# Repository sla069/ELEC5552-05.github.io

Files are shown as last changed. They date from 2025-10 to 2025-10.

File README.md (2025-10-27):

# Indoor Surveillance Drone
ELEC5552 Team 05 Indoor Surveillance Drone Project

An **autonomous indoor surveillance drone** built using the **Seeed Studio XIAO ESP32S3 Sense**, designed for **real-time monitoring, data collection, and wireless control**.  

---

## Overview

The Indoor Surveillance Drone is developed as part of a research and design project focused on indoor environmental surveillance without the use of GPS for the UWA Aviation Labs (UWAAL).  
It integrates a range of onboard sensors, live web dashboards, and local data storage to achieve semi-autonomous surveillance and sensing.

Key capabilities include:
- Real-time Wi-Fi access point (AP) control  
- Live sensor data viewing via web interface  
- Data logging in CSV format without a wired connection  
- Directional control of motors via web interface
- Live camera streaming and video recording

---

## Features

- Autonomous and manual operation modes  
- Web-based interface for live data and control  
- Wireless CSV data logging via Wi-Fi  
- Altitude, temperature, and motion sensing
- Wireless camera interface for live streaming and saving of footage to onboard microSD card

---

## Hardware Components

| Component | Description | Notes |
|---|---|---|
| **Seeed Studio XIAO ESP32S3 Sense** | Main MCU with camera and Wi-Fi | Handles all control, sensing, and communication |
| **Adafruit BMP280** | Pressure & temperature sensor | Used for altitude estimation |
| **Adafruit MPU6050** | 6-DOF IMU sensor | Provides acceleration and gyro data |
| **Li-Po Battery** | Power source | 3.7V rechargeable |
| **Drone Frame & Motors** | Propulsion system | Utilised for movement |
| **MicroSD** | Local memory | For video storage |

---

## Program Folders

This repository contains two main types of program folders, organized to make it clear which code is used for the **final demonstration** and which is for **prototyping or experiments**.

### `/src/` – Final Implemented Programs 

- Contains the **final versions** of the code used for demonstration.
- Each program is independent and can be uploaded separately to the XIAO ESP32S3.
- Subfolders:
  
/motor_control/wifi_controls.ino     → Controls drone motors and movement  
/camera_module/ESP32-CAM_MJPEG2SD.ino     → Handles camera functions and Wi-Fi streaming  
/sensor_module/combined_gyro_baro_pcb.ino       → Reads BMP280 + MPU6050 and serves web dashboard
- **Recommended for:** anyone testing or running the drone for the successfully achieved functionalities.  
- **Note:** The `camera_module` code is adapted from an open-source project ([ESP32-CAM_MJPEG2SD](https://github.com/s60sc/ESP32-CAM_MJPEG2SD)). See the `README.md` in that folder for proper attribution.

---

### `/prototype/` – Experimental and Prototype Code

- Contains **older, test, or experimental versions** of programs.
- Organized by purpose, phase, or subsystem. Example structure:

/individual_tests/→ initial motor, and sensor experiments   
/combined_versions/ → integrated tests before final firmware  
/superseded/ → older code no longer in use *(i.e for components no longer utilised in final design)*

---

## Setup and Installation

### Hardware Setup

| Connection | BMP280 | MPU6050 | Notes |
|---|---|---|---|
| **SDA** | GPIO 6  | GPIO 6  | Shared I2C line |
| **SCL** | GPIO 7  | GPIO 7  | Shared I2C line |
| **VCC** | 3.3V | 3.3V | Power supply |
| **GND** | GND | GND | Common ground |

- Power the **Seeed Studio XIAO ESP32S3** or the motor circuit via a Li-Po battery. *(depending which functionality intended to use as the motor control circuit is powered on a different board)*
- Connect the onboard camera if using the camera module and ensure ESP+camera module are not connected on the PCB connectors.   

---

### Software Setup

1. **Install Prerequisites**
   - Download and install the [Arduino IDE](https://www.arduino.cc/en/software).  
   - Add ESP32 board support:
     - Go to *File → Preferences → Additional Board Manager URLs* and add:  
       ```
       https://dl.espressif.com/dl/package_esp32_index.json
       ```
     - Then open *Tools → Board → Boards Manager*, search **ESP32**, and install it.

2. **Install Required Libraries**
   In Arduino IDE, go to *Sketch → Include Library → Manage Libraries…* and install:
   - `Adafruit BMP280`
   - `Adafruit MPU6050`
   - `Adafruit Unified Sensor`
   - `WiFi`
   - `WebServer`
   - `FS` / `SPIFFS`

3. **Clone the Repository**
   ```bash
   git clone https://github.com/<sla069>/ELEC5502-05.git
   cd ELEC5502-05

*(If you’re using Arduino IDE only, you can skip the terminal step — just click **Code → Download ZIP**, then extract the files manually.)*

### Flashing programs

1. **Select which functionality to upload.**
   - Open the desired .ino file in Arduino IDE depending on which subsystem you want to test or run.
   - Each file should be uploaded separately to the ESP dev board as a standalone program.

2. **Board Configuration**
   - Go to Tools → Board and select Seeed XIAO ESP32S3
   - Choose the correct COM port under Tools → Port.
  
3. **Compile and Upload**

4. **Access Web Interfaces**
   - For the motor module:
     - Connect to the wifi network: ESP_DRONE
     - Open your browser and navigate to: http://192.168.4.1/

   - For the sensors:
     - Connect to the wifi network: Drone_sensors
     - Open your browser and navigate to: http://192.168.4.1/
    
   - For the camera module:
     - Connect to the wifi network: Drone Live Footage
     - Open your browser and navigate to: http://192.168.4.1/

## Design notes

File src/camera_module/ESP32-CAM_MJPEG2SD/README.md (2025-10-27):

# Camera Module Code Notice

This folder contains firmware adapted from an **open-source project** to provide camera functionality for the indoor surveillance drone.

---

## ⚠️ Disclaimer

The source code in this folder is **based on or modified from** the following open-source repository:

[ESP32-CAM_MJPEG2SD by s60sc](https://github.com/s60sc/ESP32-CAM_MJPEG2SD)

All credit for the original implementation belongs to the original author(s) of that repository.  
This code may have been **modified** to suit the integration needs of this project (e.g., for use with the Seeed Studio XIAO ESP32S3, different pin mappings, or simplified configuration).

---

## License Notice

The original repository is licensed under its respective open-source license.  
Please refer to that project’s license terms before redistribution or commercial use.

Any changes or adaptations made in this folder are clearly documented in comments within the source code.

---
# ESP32-CAM_MJPEG2SD

### ***Not yet compatible with latest arduino-esp32 core v3.3.0 as espressif have changed the jpeg decoder - issue [#628](https://github.com/s60sc/ESP32-CAM_MJPEG2SD/issues/628), use v3.2.1***

Application for ESP32 / ESP32S3 with OV2640 / OV3660 / OV5640 camera to record JPEGs to SD card as AVI files and playback to browser as an MJPEG stream. The AVI format allows recordings to replay at correct frame rate on media players. If a microphone is installed then a WAV file is also created and stored in the AVI file.  
The application supports:
* [Motion detection by camera](#motion-detection-by-camera) or PIR / radar sensor
* Time lapse recording
* [Audio Recording](#audio-recording) from I2S or PDM microphones
* Camera pan / tilt servos and lamp control
* [RTSP Server](#rtsp) stream Video, Audio and Subtitles
* [Telemetry Recording](#telemetry-recording) during camera recording.
* [Remote Control](#remote-control) of camera mounted vehicle.
* Alert notification using [Telegram](#telegram-bot) or Email
* Concurrent streaming to web browser and [remote NVR](#stream-to-nvr) using HTTP or RTSP
* Transfer recordings using FTP, HTTPS, [WebDAV](#webdav), or download from browser
* [MQTT](#mqtt) control with Home Assistant integration.
* [External Heartbeat](#external-heartbeat) support.
* Support for peripherals: SG90 servos, MX1508 H-bridge, 28BYJ-48 stepper, HW-504 joystick, BMP280, MPU9250, MY9221 / WS2812 / SK6812 Led
* Support for [I2C devices](#i2c-devices): BMP280, BME280, MPU6050, MPU9350, SSD1306, LCD1602, etc.
* Interface for [Machine Learning](#machine-learning) support.
* [Camera Hub](#camera-hub) feature to access other ESP32-CAM_MJPEG2SD devices.
* [Photogrammetry](#photogrammetry) feature to capture photos for 3D imaging.
* Use of [Auxiliary Board](#auxiliary-board) for additional pins.
* [Intercom](#intercom) feature using mic and speaker on ESP and mic and speaker on user device browser.

The ESP32 cannot support all of the features as it will run out of heap space. For better functionality and performance, use one of the new ESP32S3 camera boards, eg Freenove ESP32S3 Cam, ESP32S3 XIAO Sense, but avoid no-name boards marked `ESPS3 RE:1.0`

***This is a complex app and some users are raising issues when the app reports a warning, but this is the app notifying the user that there is an problem with their setup, which only the user can fix. Be aware that some clone boards have different specs to the original, eg PSRAM size. Please only raise issues for actual bugs (ERR messages, unhandled library error or crash). Thanks.  
To suggest an improvement or enhancement use Discussions.*** 

Changes up to version 10.6:
* Stream to [NVR](#stream-to-nvr) using integration to RTSPServer library contributed by [@rjsachse](https://github.com/rjsachse). 
* Frame resolution selection mismatch corrected due to [#10801](https://github.com/espressif/arduino-esp32/issues/10801) in arduino core v3.1.0
* SD card 4 bit mode configurable (see `utilsFS.cpp`)
* Shared I2C fixed following code changes in Arduino core v3.1.1
* 24Mhz camera clock available for faster frame rate on ESP32S3, contributed by [@josef2600](https://github.com/josef2600).
* RTSP server now has multiple client support as well as user/pass authentication.
* Limited support added for boards with only 2MB PSRAM

## Purpose

The application enables video capture of motion detection or timelapse recording. Examples include security cameras, wildlife monitoring, rocket flight monitoring, FPV vehicle control.  This [instructable](https://www.instructables.com/How-to-Make-a-WiFi-Security-Camera-ESP32-CAM-DIY-R/) by [Max Imagination](https://www.instructables.com/member/Max+Imagination/) shows how to build a WiFi Security Camera using an earlier version of this code, plus a later video on how to [install and use](https://www.youtube.com/watch?v=k_PJLkfqDuI&t=247s) the app.

Saving a set of JPEGs as a single file is faster than as individual files and is easier to manage, particularly for small image sizes. Actual rate depends on quality and size of SD card and complexity and quality of images. A no-name 4GB SDHC labelled as Class 6 was 3 times slower than a genuine Sandisk 4GB SDHC Class 2. The following recording rates were achieved on a freshly formatted Sandisk 4GB SDHC Class 2 on a AI Thinker OV2640 board, set to maximum JPEG quality and clock rate of 20MHz. With a clock rate of 24Mhz on ESP32S3, the maximum frame rates can increase 50->60, 25->30 but it may be necessary to reduce JPEG quality.

Frame Size | OV2640 camera max fps | mjpeg2sd max fps | Detection time ms
------------ | ------------- | ------------- | -------------
96X96 | 50 | 45 |  15
QQVGA | 50 | 45 |  20
QCIF  | 50 | 45 |  30
HQVGA | 50 | 45 |  40
240X240 | 50 | 45 |  55
QVGA | 50 | 40 |  70
CIF | 50 | 40 | 110
HVGA | 50 | 40 | 130
VGA | 25 | 20 |  80
SVGA | 25 | 20 | 120
XGA | 12.5 | 5 | 180
HD | 12.5 | 5 | 220
SXGA | 12.5 | 5 | 300
UXGA | 12.5 | 5 | 450

The ESP32S3 (using Freenove ESP32S3 Cam board hosting ESP32S3 N8R8 module) runs the app about double the speed of the ESP32 mainly due to much faster PSRAM. It can record at the maximum OV2640 frame rates including [audio](#audio-recording) for all frame sizes except UXGA (max 10fps).

## Design

The ESP32 Cam module has 4MB of PSRAM (8MB on most ESP32S3) which is used to buffer the camera frames and the construction of the AVI file to minimise the number of SD file writes, and optimise the writes by aligning them with the SD card sector size. For playback the AVI is read from SD into a multiple sector sized buffer, and sent to the browser as timed individual frames. By dewfault the SD card is used in **MMC 1 line** mode, as this is practically as fast as **MMC 4 line** mode on the ESP32 and frees up pin 4 (connected to onboard Lamp), and pin 12 which can be used for eg a PIR. On the ESP32S3 however, tests by [@josef2600](https://github.com/josef2600) indicate that **MMC 4 line** mode provides a [doubling](https://github.com/s60sc/ESP32-CAM_MJPEG2SD/issues/529#issuecomment-2588088722) of speed.  

The AVI files are named using a date time format **YYYYMMDD_HHMMSS** with added frame size, FPS recording rate, duration in secs, eg **20200130_201015_VGA_15_60.avi**, and stored in a per day folder **YYYYMMDD**. If audio is included the filename ends with **_S**.  If telemetry is available the filename ends with **_M**.  
The ESP32 time is set from an NTP server or connected browser client.

## Installation

Download github files into the Arduino IDE sketch folder, removing `-master` from the application folder name.
Compile with at least arduino-esp32 core v3.1.1 which contains network fixes and frame selection changes.
Select the required ESP-CAM board by uncommenting ONE only of the `#define CAMERA_MODEL_*` in `appGlobals.h` unless using the one of the defaults:
* ESP32 Cam board - `CAMERA_MODEL_AI_THINKER`
* Freenove ESP32S3 Cam board - `CAMERA_MODEL_FREENOVE_ESP32S3_CAM`  

Optional features are not included by default. To include a feature, in `appGlobals.h` set relevant `#define INCLUDE_*` to `true`. 

Select the ESP32 or ESP32S3 Dev Module board and compile with PSRAM enabled and the following Partition scheme:
* ESP32 - `Minimal SPIFFS (...)`
* ESP32S3 - `8M with spiffs (...)` or `16MB(3MB APP...)`

**NOTE:**
* **If you get compilation errors you need to update your `arduino-esp32` core library in the IDE to latest v3.x
using [Boards Manager](https://github.com/s60sc/ESP32-CAM_MJPEG2SD/issues/61#issuecomment-1034928567)**
* **If you get error: `Startup Failure: Check SD card inserted`, or `Camera init error 0x105` it is usually a [camera board selection](https://github.com/s60sc/ESP32-CAM_MJPEG2SD/issues/219#issuecomment-1627785417) issue**
* **If you get warning: `Crash loop detected, check log`, it is usually an inadequate power supply.**

On first installation, the application will start in wifi AP mode - connect to SSID: **ESP-CAM_MJPEG_...**, to allow router to be selected and router password entered via the web page on `192.168.4.1`. The configuration data file (except passwords) is automatically created, and the application web pages automatically downloaded from GitHub to the SD card **/data** folder when an internet connection is available.

Subsequent updates to the application, or to the **/data** folder files, can be made using the **OTA Upload** tab. The **/data** folder can also be reloaded from GitHub using the **Reload /data** button on the **Edit Config** tab, or by using a WebDAV client.

An alternative installation process by [@ldijkman](https://github.com/ldijkman) is described [here](https://youtu.be/YLLGBM3i2aQ).

Browser functions only fully tested on Chrome.

## Main Function

A recording is generated either by the camera itself detecting motion, or by holding a given pin high (kept low by internal pulldown when released), eg by using an active high motion sensor such as PIR or RCWL-0516 microwave radar.
In addition a recording can be requested manually using the **Start Recording** button on the web page.

To play back a recording, select the file using **Playback & File Transfers** sidebar button to select the day folder then the required AVI file.
After selecting the AVI file, press **Start Playback** button to playback the recording. 
The **Start Stream** button shows a live video only feed from the camera. 

Recordings can then be uploaded to an FTP or HTTPS server or downloaded to the browser for playback on a media application, eg VLC.
To incorporate FTP or HTTPS server, set `#define INCLUDE_FTP_HFS` to `true`.

A time lapse feature is also available which can run in parallel with motion capture. Time lapse files have the format **20200130_201015_VGA_15_60_T.avi**

## Other Functions and Configuration

The operation of the application can be modified dynamically as below, by using the main web page, which should mostly be self explanatory.

Connections:
* The FTP / HTTPS, Wifi, SMTP, and time zone parameters can be defined in **Access Settings** sidebar button. 
  - for **Time Zone** use dropdown, or paste in values from second column [here](https://raw.githubusercontent.com/nayarsystems/posix_tz_db/master/zones.csv)
* To make the changes persistent, press the **Save** button
* mdns name services in order to use `http://[Host Name]` instead of ip address.

To change the recording parameters:
* `Resolution` is the pixel size of each frame
* `Frame Rate` is the required frames per second
* `Quality` is the level of JPEG compression which affects image size.

SD storage management:
* Folders or files within folders can be deleted by selecting the required file or folder from the drop down list then pressing the **Delete** button and confirming.
* Folders or files within folders can be uploaded to a remote server via FTP / HTTPS by selecting the required file or folder from the drop down list then pressing the **File Upload** button. Can be uploaded in AVI format.
* Download selected AVI file from SD card to browser using **Download** button.
* Delete, or upload and delete oldest folder when card free space is running out.  

View application log via web page, displayed using **Show Log** tab:
  * Select log type for display:
    * RTC RAM: Cyclic 7KB log saved in RTC RAM (default)
    * Websocket: log is dynamically output via websocket
    * SD card: Unlimited size log saved to SD card
  * Use slider to enable SD logging, but can slow recording rate
  * Use buttons to refresh or clear selected log

## Configuration Web Page

More configuration details accessed via **Edit Config** tab, which displays further buttons:

**Wifi**:
Additional WiFi and webserver settings.

**Motion**: 
See [**Motion detection by Camera**](#motion-detection-by-camera) section.

**Peripherals** eg:
* Select if a PIR or radar sensor is to be used (which can also be used in parallel with camera motion detection).
* Control pan / tilt cradle for camera.
* Connect a PDM or I2S microphone and I2S amplifier.
* Connect a DS18B20 temperature sensor.
* Monitor voltage of battery supply on ADC pin.
* Wakeup on LDR after deep sleep at night.

To incorporate peripherals, set `#define INCLUDE_PERIPH` to `true`.

The **Peripherals** tab also enables further config tabs to be displayed:
* **Audio**: to configure microphones and amplifiers.
* **RC Config**: to configure hardware for remote control vehcles.
* **Servos**: to configure servos for camera control and RC steering
* **PG Control**: to configure and control hardware for photogrammetry.  

After changes are applied, need to press `Save` then `Reboot ESP` to restart peripherals with changes.

Note that there are not enough free pins on the ESP32 camera module to allow all external sensors to be used. Pins that can be used (with some limitations) are: 3, 4, 12, 13, 26, 27 32, 33.
* pin 3: Labelled U0R. Only use as input pin, as also used for flashing. 
* pin 4: Also used for onboard lamp. Lamp can be disabled by removing its current limiting resistor. 
* pin 12: Only use as output pin.
* pin 13: Is weakly pulled high.
* pins 26, 27: I2C pins shareable with camera - see [I2C devices](#i2c-devices)
* pin 32: Controls camera power on / off. Not broken out, but with electronics knowledge can be disconnected leaving camera permanently on by referring to the board schematic.
* pin 33: Used by onboard red LED. Not broken out, but can repurpose the otherwise pointless VCC pin by removing its adjacent resistor marked 3V3, and the red LED current limiting resistor, then running a wire between the VCC pin and the red LED resistor solder tab.

Do not use any other exposed pin including pin 16 used by PSRAM.

The ESP32S3 Freenove board can support multiple peripherals with its spare pins.
The ESP32S3 XIAO Sense board has fewer free pins but more than the ESP32.

On-board LEDs:
* ESP32: Lamp 4, signal 33.
* ESP32S3:
  * Freenove: Lamp 48, signal 2.
  * XIAO: Lamp n/a, signal 21.

**Other**:
SD, email, telegram, etc management. To icorporate email (SMTP), set `#define INCLUDE_SMTP` to `true`.

When a feature is enable or disabled, the **Save** button should be used to persist the change, and the ESP should be rebooted using **Reboot ESP** button.

## Motion detection by Camera

An AVI recording can be generated by the camera itself detecting motion using the `motionDetect.cpp` file.  
JPEG images of any size are retrieved from the camera and 1 in N images are sampled on the fly for movement by decoding them to very small grayscale bitmap images which are compared to the previous sample. The small sizes provide smoothing to remove artefacts and reduce processing time.

For movement detection a high sample rate of 1 in 2 is used. When movement has been detected, the rate for checking for movement stop is reduced to 1 in 10 so that the JPEGs can be captured with only a small overhead. The **Detection time ms** table shows typical time in millis to decode and analyse a frame retrieved from the OV2640 camera.

Motion detection by camera is enabled by default, to disable click off **Enable motion detect** in **Motion Detect & Recording** sidebar button. Motion detection is not available for frame sizes > SXGA due to limitations with `esp_jpg_decode()`.



Additional options are provided on the camera index page, where:
* `Motion Sensitivity` sets a threshold for movement detection, higher is more sensitive.
* `Show Motion` if enabled and the **Start Stream** button pressed, shows images of how movement is detected for calibration purposes. Grayscale images are displayed with red pixels showing movement.
* `Min Frames` is the minimum number of frames to be captured or the file is deleted.  

## Audio Recording

An I2S microphone eg INMP441 is supported by both ESP32 and ESP32S3. A PDM microphone eg MP34DT01 is only supported on ESP32S3. Audio recording works fine on ESP32S3 but is not viable on ESP32 as it significantly slows down the frame rate. 

The audio is formatted as 16 bit single channel PCM with sample rate of 16kHz. An I2S microphone needs 3 free pins, a PDM microphone needs 2 free pins (the I2S SCK pin must be set to -1). Pin values (predefined for XIAO Sense) are set under **Audio** button on the configuration web page.

The web page has a slider for **Microphone Gain**. The higher the value the higher the gain for ESP microphone. Selecting **0** cancels the microphone.

The Speaker icon button on the web page can be used to listen to the microphone from the browser.

To incorporate, set `#define INCLUDE_AUDIO` to `true`.

## Intercom

The intercom feature allows two way conversation between an ESP32 with microphone and amplifier / speaker installed and the device hosting the app web page where the browser has access to the host device microphone and speaker. Access to the device microphone may have security constraints, see `audio.cpp`. This feature is only viable on an ESP32S3 and needs a good WiFi connection and spatial separation at both ends to prevent a feedback loop.

An I2S amplifier needs 1 free pin on the ESP32S3 if an I2S microphone is installed as they can share the clock pins. Pin values are set under **Audio** button on the configuration web page. 

The web page has a slider for **Amplifier Volume**. The higher the value the higher the volume for ESP speaker. Selecting **0** cancels the speaker.

On the left side on the main web page are icons for browser device microphone and speaker. Selecting the icon (if not grayed out) activates the browser microphone or speaker. 

## OV5640

The OV5640 pinout is compatible with boards designed for the OV2640 but the voltage supply is too high for the internal 1.5V regulator, so the camera overheats unless a heat sink is applied.

For recording purposes the OV5640 should only be used with an ESP32S3 board. Frame sizes above `FHD` framesize should only be used for still images due to memory limitations.

Recordable frame rates for the OV5460 highest framesizes on an ESP32S3 are:

Frame Size | FPS 
------------ | -------------
QXSGA | 4
WQXGA | 5
QXGA | 5
QHD | 6
FHD | 6
P_FHD | 6

## Auxiliary Board

To free up pins on the camera board, this app can be installed on both a camera board and an auxiliary board with the latter hosting hardware such as BDC motors, steppers and servos. 
The communication with the auxiliary board can be either of:
* Instead of the commands from the app web page being set to the camera board, they are redirected to the 
auxiliary board
* The cam board forwarding commands from the app web page to the auxiliary board over a UART connection.

The auxiliary board can be used to drive the hardware for:
* RC speed, steering and lights real time control.
* Camera pan and tilt.
* Photogrammetry operation.

 Instal app on camera board in usual way. Under **Peripherals** tab, either:
 * Enter IP address of the auxiliary board in field: `Send RC / Servo / PG commands to auxiliary IP` then save and reboot. Relevant commands from cam board web page will now be sent to the auxiliary board. 
 * Enter UART pin numbers and select `Use UART for Auxiliary connection`, then save and reboot. Relevant commands from cam board web page will be sent to the cam board then forwarded to the auxiliary board. 
 
 Instal app on auxiliary board after uncommenting ONLY `#define AUXILIARY` in camera selection block in `appGlobals.h`. The auxiliary board does not need camera, SD card or PSRAM, just wifi and enough pins to connect to the relevant hardware. Note that MCPWM for BDC motors is not supported by ESP32-C3.  
 
 The Auxil web page on the auxiliary board is a cut down version of the camera app web page. The configuration details under **RC Config**, **Servo Config** and **PG Config** tabs must be entered on the auxiliary board web page, not the cam web page. If using UART, enter relevant pin numbers on both web pages and wire RX to TX between boards plus a common ground.
 
To incorporate, set `#define INCLUDE_UART` to `true`.

## MQTT

To enable MQTT, under **Edit Config** -> **Others** tab, enter fields:
* `Mqtt server ip to connect`
* `Mqtt topic path prefix`
* optionally `Mqtt user name` and `Mqtt user password`
* Then set `Mqtt enabled` 

MQTT will auto connect if configuration is not blank on ping success.

It will send messages e.g. Record On/Off Motion On/Off to the mqtt broker on channel /status.  
topic: `homeassistant/sensor/{esp cam hostname}/state -> {"MOTION":"ON", "TIME":"10:07:47.560"}`

You can also publish control commands to the /cmd channel in order to control camera.
topic: `homeassistant/sensor/{esp cam hostname}/cmd -> dbgVerbose=1;framesize=7;fps=1`

To incorporate, set `#define INCLUDE_MQTT` to `true`.

### Home assistant MQTT camera integration

Integration with Home Assistant [MQTT Camera](https://www.home-assistant.io/integrations/camera.mqtt/) contributed by [@gemi254](https://github.com/gemi254) - send mqtt discovery messages to:
* publish an image payload on motion detection that will be displayed on the dashboard
* automatically create a home assistant camera device inside mqtt devices integration.
* publish motion on/off messages on channel `homeassistant/sensor/{esp cam hostname}/motion` that can be used for home automations.
* publish an image payload on motion detection that will be displayed on the dashboard.

To incorporate set `#define INCLUDE_HASIO` to `true`.



## External Heartbeat

Contributed by [@alojzjakob](https://github.com/alojzjakob), see also https://github.com/alojzjakob/EspSee

Allow access to multiple cameras behind single dynamic IP with different ports port-forwarded through the router. Another limitation was to avoid using DDNS because it was hard/impossible to set up on given router.
You will be able to easily construct list of your cameras with data contained in JSON sent to your server/website.

To enable External Heartbeat, under **Edit Config** -> **Others** tab, enter fields:
* `Heartbeat receiver domain or IP` (e.g. www.espsee.com)
* `Heartbeat receiver URI` (e.g. /heartbeat/)
* `Heartbeat receiver port` (443 for ssl, 80 for non-ssl, or your custom port)
* optionally `Heartbeat receiver auth token` (if you use EspSee, it will provide auth token for your user account)
* Then set `External Heartbeat Server enabled` 

Heartbeat will be sent every 30 (default) seconds. It will do a POST request to defined domain/URI (i.e. www.mydomain.com/my-esp32cam-hub/index.php) with JSON body, containing useful information you might need for your specific application.

If you are using EspSee, it will do a POST request to defined domain/URI (i.e. https://www.espsee.com/heartbeat/?token=[your_token]) with JSON body, containing useful information about your camera allowing this website to connect it to your user account and provide a way to easily access your camera(s) without the need for DDNS.

If you want to have multiple cameras accessible from the same external IP (behind router) you might need to do port forwarding and set ports on EspSee camera entries accordingly.

To incorporate, set `#define INCLUDE_EXTHB` to `true`.

## Port Forwarding

To access the app remotely over the internet, set up port forwarding on your router for browser on HTTP port, eg:



On remote device, enter url: `your_router_external_ip:10880`  
To obtain `your_router_external_ip` value, use eg: https://api.ipify.org  
Set a static IP address for your ESP camera device.  
For security, **Authentication settings** should be defined in **Access Settings** sidebar button.

Note that some internet providers will use [CGNAT](https://en.wikipedia.org/wiki/Carrier-grade_NAT), which will make port forwarding hard to achieve or impossible (you might need to contact your ISP and ask them for a solution if they are willing to help).

## I2C Devices

**I2C sharing not available in arduino core v3.1.1 due to camera library [issue](https://github.com/espressif/esp32-camera/issues/718). 
Use separate I2C port.**



Multiple I2C devices can share the same two I2C pins. As the camera also uses I2C then the other devices can either share the camera I2C pins or use a separate I2C port. The shared I2C concept was contributed by [@rjsachse](https://github.com/rjsachse). 

The former approach saves pins, particularly on the ESP32, but generally ESP32 cam boards do not have the pins exposed so some soldering of wires is required. The ESP32S3 boards generally have all pins exposed.  

The image shows how wires can be connected to the shared I2C port on the ESP32 AI Thinker style cams. The orange wire is the SDA pin (GPIO26) and the white wire is the SCL pin (GPIO27). Each wire is soldered to the top of an on-board resistor.

By default, the I2C port is shared with the camera, but a separate port can be used by defining alternative SDA and SCL pins under the **Peripherals** tab.

To incorporate I2C support, set `#define INCLUDE_I2C` to `true`.
To enable a particular I2C device, set corresponding `#define USE_*` to `true` in `appGlobals.h`.

## Telemetry Recording

This feature is better used on an ESP32S3 camera board due to performance and memory limitations on ESP32.

Telemetry such as environmental and motion data (eg from BMP280 and MPU9250 on GY-91 board) can be captured during a camera recording. It is stored in a separate CSV file for presentation in a spreadsheet. The CSV file is named after the corresponding AVI file. A subtitle (SRT) file is also created named after the corresponding AVI file. The CSV and SRT files are uploaded or deleted along with the corresponding AVI file. For downloading, the AVI, CSV and SRT files are bundled into a zip file. If the SRT file is in the same folder as the AVI file, telemetry data subtitles will be displayed by a media player. 

The user needs to add the code for the required sensors to the file `telemetry.cpp`. Contains simple example for the BMP280 and MPU9250 devices.

To switch on telemetry recording, select the `Use telemetry recording` option bunder the **Peripherals** button. The frequency of data collection is set by `Telemetry collection interval (secs)`.

Note: esp-camera library [conflict](https://forum.arduino.cc/t/conflicitng-declaration-in-adafruit_sensor-esp32-camera/586568) if use Adafruit sensor library.

To incorporate, set `#define INCLUDE_TELEM` to `true`.

## Telegram Bot

Only enable one of Telegram or SMTP email.  
Use [IDBot](https://t.me/myidbot) to obtain your Chat ID.  
Use [BotFather](https://t.me/botfather) to create a Telegram Bot and obtain the Bot Token.  
In **Edit Config** page under **Other** tab, paste in `Telegram chat identifier` and `Telegram Bot token` and select `Use Telegram Bot`.  
You may want to make the bot private.  
Note that this feature uses a lot of heap space due to TLS.

The Telegram Bot will now receive motion alerts from the app showing a frame from the recording with a caption containing a command link for the associated recording (max 50MB) which can be downloaded and played.  

To incorporate, set `#define INCLUDE_TGRAM` to `true`.



## Remote Control

Provides for remote control of device on which camera is mounted, e.g RC vehicle for FPV etc.  
Best used with ESP32-S3 for frame rate and control responsiveness.

To enable, in **Edit Config** page under **Peripherals**, select `Enable remote control`, then save and reboot
This will show an extra config button **RC Config**.  
Pressing the **RC Config** button will allow pins to be defined for:
- SG90 type steering servo
- H-bridge motor control (tested with MX1508)
- On / off lights
- Further parameters for vehicle control.

Steering can either be provided by servo control, or by track steering using separately controlled left and right side motors.

The streaming view will now have a red button in the top left. Press this to show / hide overlaid steering and motor controls. Camera view buttons can be used to change to full screen. Tethered vehicles can also be controlled via a HW-504 type joystick. Camera view (and microphone and telemetry if enabled) can be recorded.  
Motion detection should be disabled beforehand.  

This feature can make use of an [Auxiliary Board](#auxiliary-board).  

To incorporate, set `#define INCLUDE_PERIPH` to `true` and `#define INCLUDE_MCPWM` to `true`.

#### Only use this feature if you are familiar with coding and electronics, and can fix issues yourself

## Machine Learning

Machine Learning AI can be used to further discriminate whether to save a recording when motion detection has occurred by classsifying whether the object in the frame is of interest, eg a human, type of animal, vehicle etc. 

Only feasible on ESP32S3 due to memory use and built in AI Acceleration support.
#### Only use this feature if you are familiar with Machine Learning

The interface is designed to work with user models packaged as Arduino libraries by the [Edge Impulse](https://edgeimpulse.com/) AI platform.
More details in `appGlobals.h`.   

Use 96x96 grayscale or RGB images and train the model with for example the following Transfer learning Neural Network settings:  



## Camera Hub

This tab enables the web interfaces of other ESP32-CAM_MJPEG2SD camera devices to be accessed. To show this tab, in **Edit Config** page under **Other**, select `Show Camera Hub tab`.  

In the tab, enter IP address of another camera and press **Add IP** button, a screen showing an image from the camera is displayed with its IP address overlayed. Repeat for each camera to be monitored. Click on an image to open the web page for that camera.  

Press **X** icon on image to remove that IP address. Press **Delete All** button to remove all IP addresses. Press **Refresh** button to update each screen with the latest image from that camera.  

The IP addresses are stored in the browser local storage, not the app itself.

## Stream to NVR

This feature is better used on an ESP32S3 camera board due to performance and memory limitations on ESP32.

Either HTTP or RTSP can be used, but not together. RTSP is more sophisticated.

Streaming performance depends on quality of network connection, but can be increased by switching off motion detection, as if a recording occurs during streaming it will take priority and the streams may stutter.

#### RTSP

This requires an additional library to be installed - see [RTSPServer](https://github.com/rjsachse/ESP32-RTSPServer) library for details. Must be version 1.3.1 or above

To integrate library with this app, set `#define INCLUDE_RTSP` to `true`.

To enable RTSP, under **Edit Config** -> **Streaming** tab, select: 
* `Enable RTSP Video` for video stream
* `Enable RTSP Audio` for audio stream (need to setup [microphone](#audio-recording) beforehand).
* `Enable RTSP Subtitles` for subtitle stream (need to setup [telemetry](#telemetry-recording) beforehand, otherwise just a timestamp and FPS will be output)

Then save and reboot. 

To view the stream, connect to `rtsp://<camera_ip>:<RTSPport>` using app supporting RTSP.

Or if authentication is enabled (username and password):
`rtsp://<RTSPuser>:<RTSPpass>@<camera_ip>:<RTSPport>`

RTSP now supports multiple clients for multicast. You can also override this logic and enable multiple clients for all transports (TCP, UDP, Multicast) by commenting out //#define OVERRIDE_RTSP_SINGLE_CLIENT_MODE in rtsp.cpp. 
However, enabling multiple clients for all transports can slow the stream down and may cause issues, so use with care. It is better to leave it for only one client if using TCP or UDP unicast for best results. For more details, 
check out the README in the RTSPServer library.

#### HTTP

HTPP streaming is available if `#define INCLUDE_RTSP` is set to `false`.

Streams separate from the web browser are available for capture by a remote NVR. To enable these streams, under **Edit Config** -> **Streaming** tab, select: 
* `Enable Video stream on /sustain?video=1` for MJPEG stream
* `Enable Audio stream on /sustain?audio=1` for WAV stream (need to setup [microphone](#audio-recording) beforehand).
* `Enable Subtitle stream on /sustain?srt=1` for SRT stream (need to setup [telemetry](#telemetry-recording) beforehand, otherwise just a timestamp will be output).

Then save and reboot. 

If multiple streams are enabled they need to be processed by an intermediate tool for synchronisation, eg [go2rtc](https://github.com/AlexxIT/go2rtc) (but which does not handle subtitles [yet?](https://github.com/AlexxIT/go2rtc/issues/932)). See [ESP32-CAM_Audio](https://github.com/spawn451/ESP32-CAM_Audio#usage) for go2rtc configuration examples. 

## WebDAV

A simple WebDAV server is included. A WebDAV client such as Windows 10 File Explorer can be used to access and manage the SD card content. In a folder's address bar enter `<ip_address>/webdav`, eg `192.168.1.132/webdav`  
For Windows 11, Android, MacOS, Linux see `webDav.cpp` file.

To incorporate, set `#define INCLUDE_WEBDAV` to `true`



## Photogrammetry

ESP can be used to capture a series of photographs of small objects, controlling a stepper motor driven turntable, using either the ESP camera for low resolution images, or a DSLR camera for high resolution images remotely controlled by the ESP. The captured images can be used to generate a 3D model.  

To enable this feature, in **Edit Config** page under **Peripherals**, select `Enable photogrammetry`, then save and reboot.  
This will show an extra config button **PG Config**. Pressing this button will bring up options for controlling the photogrammetry process.  

This feature can make use of an [Auxiliary Board](#auxiliary-board).  

See `photogram.cpp` for more information. To incorporate, set `#define INCLUDE_PGRAM` to `true`

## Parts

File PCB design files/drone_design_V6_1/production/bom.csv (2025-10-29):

Designator | Footprint | Quantity | Value | LCSC Part #
C1, C10, C2, C3, C4, C9 | 0805 | 6 | 100nF
C5, C8 | 0805 | 2 | 0.1uF
C6, C7 | 0805 | 2 | 0.01uF
D1, D2, D3, D4 | D_SOD-123 | 4 | 1N4148
J1, J2 | SAMTEC_SSM-107-L-SV | 2 | SSM-107-L-SV
J3 | CONN4X1_NPTC041KFXC-RC_SUL | 1 | NPTC041KFXC-RC
Q1, Q2, Q3, Q4 | SOT-23 | 4 | SI2300
R1, R10, R11, R12, R13, R2, R3, R4, R5, R6, R7, R8, R9 | 0805 | 13 | 10k
TP1, TP2, TP3, TP4, TP5, TP6, TP7, TP8 | TestPoint_Pad_D1.5mm | 8 | TestPoint
TP10, TP9 | TestPoint_Pad_D1.0mm | 2 | TestPoint
U2 | InvenSense_QFN-24_4x4mm_P0.5mm | 1 | MPU-6050
U3 | XDCR_BMP280 | 1 | BMP280

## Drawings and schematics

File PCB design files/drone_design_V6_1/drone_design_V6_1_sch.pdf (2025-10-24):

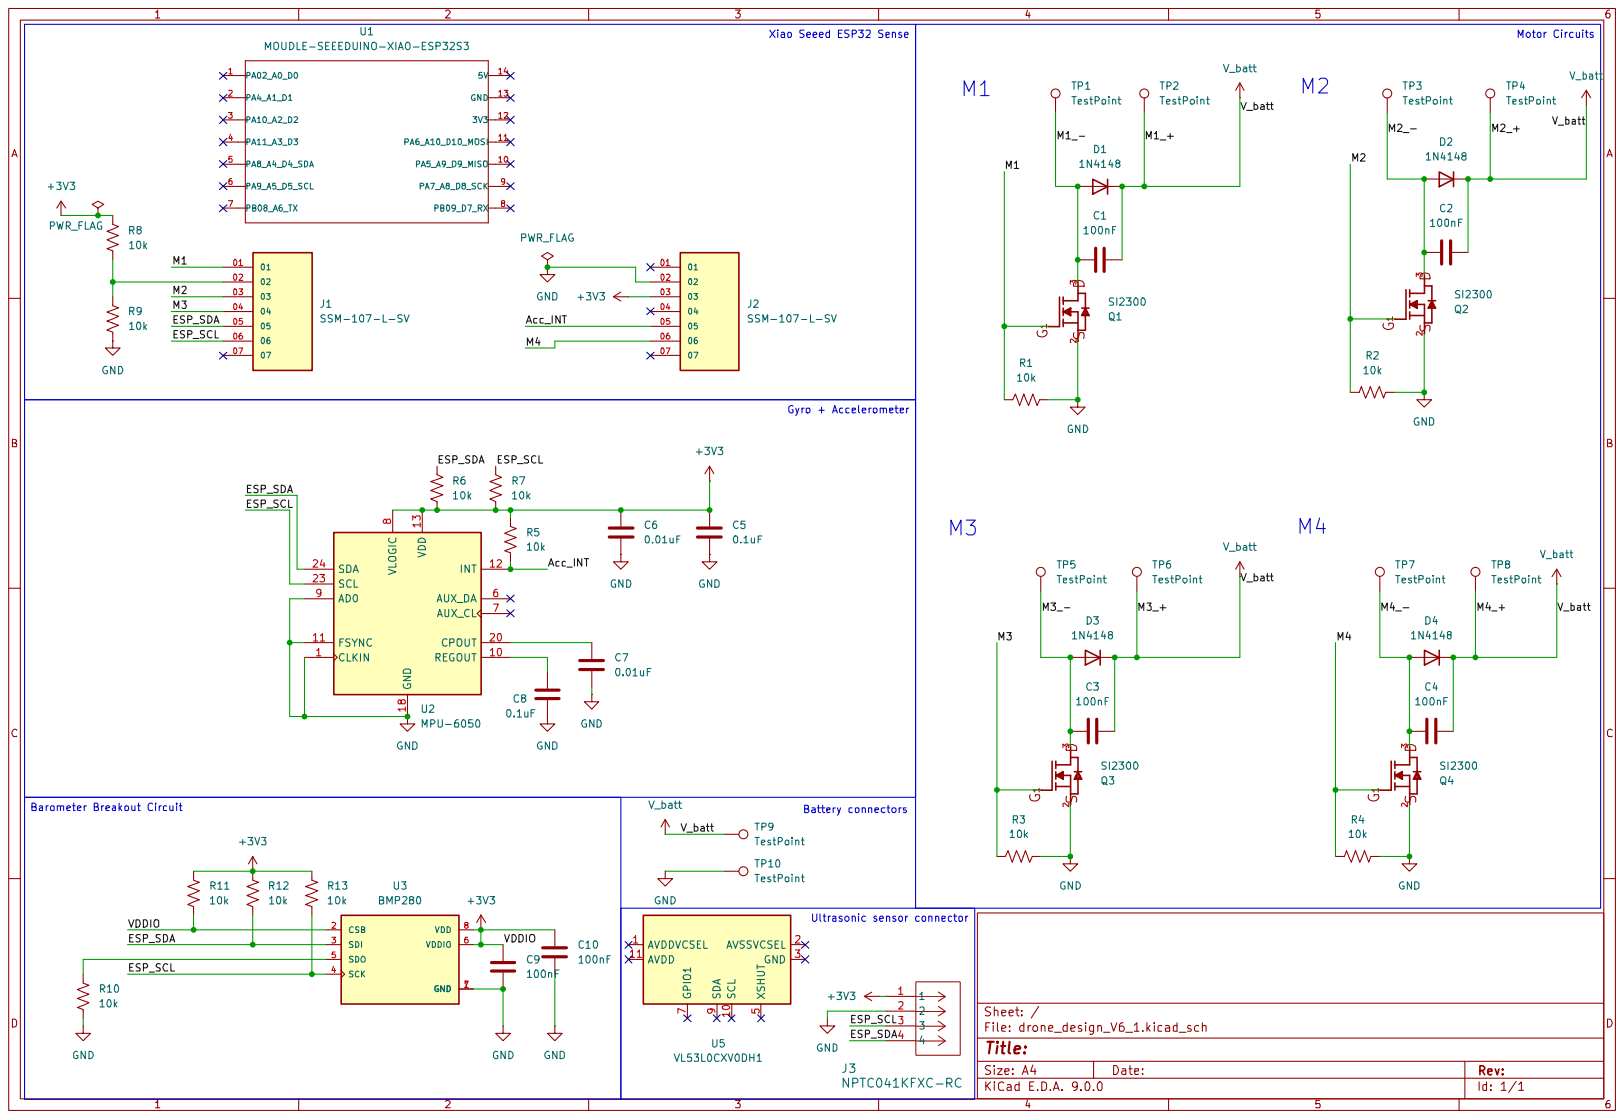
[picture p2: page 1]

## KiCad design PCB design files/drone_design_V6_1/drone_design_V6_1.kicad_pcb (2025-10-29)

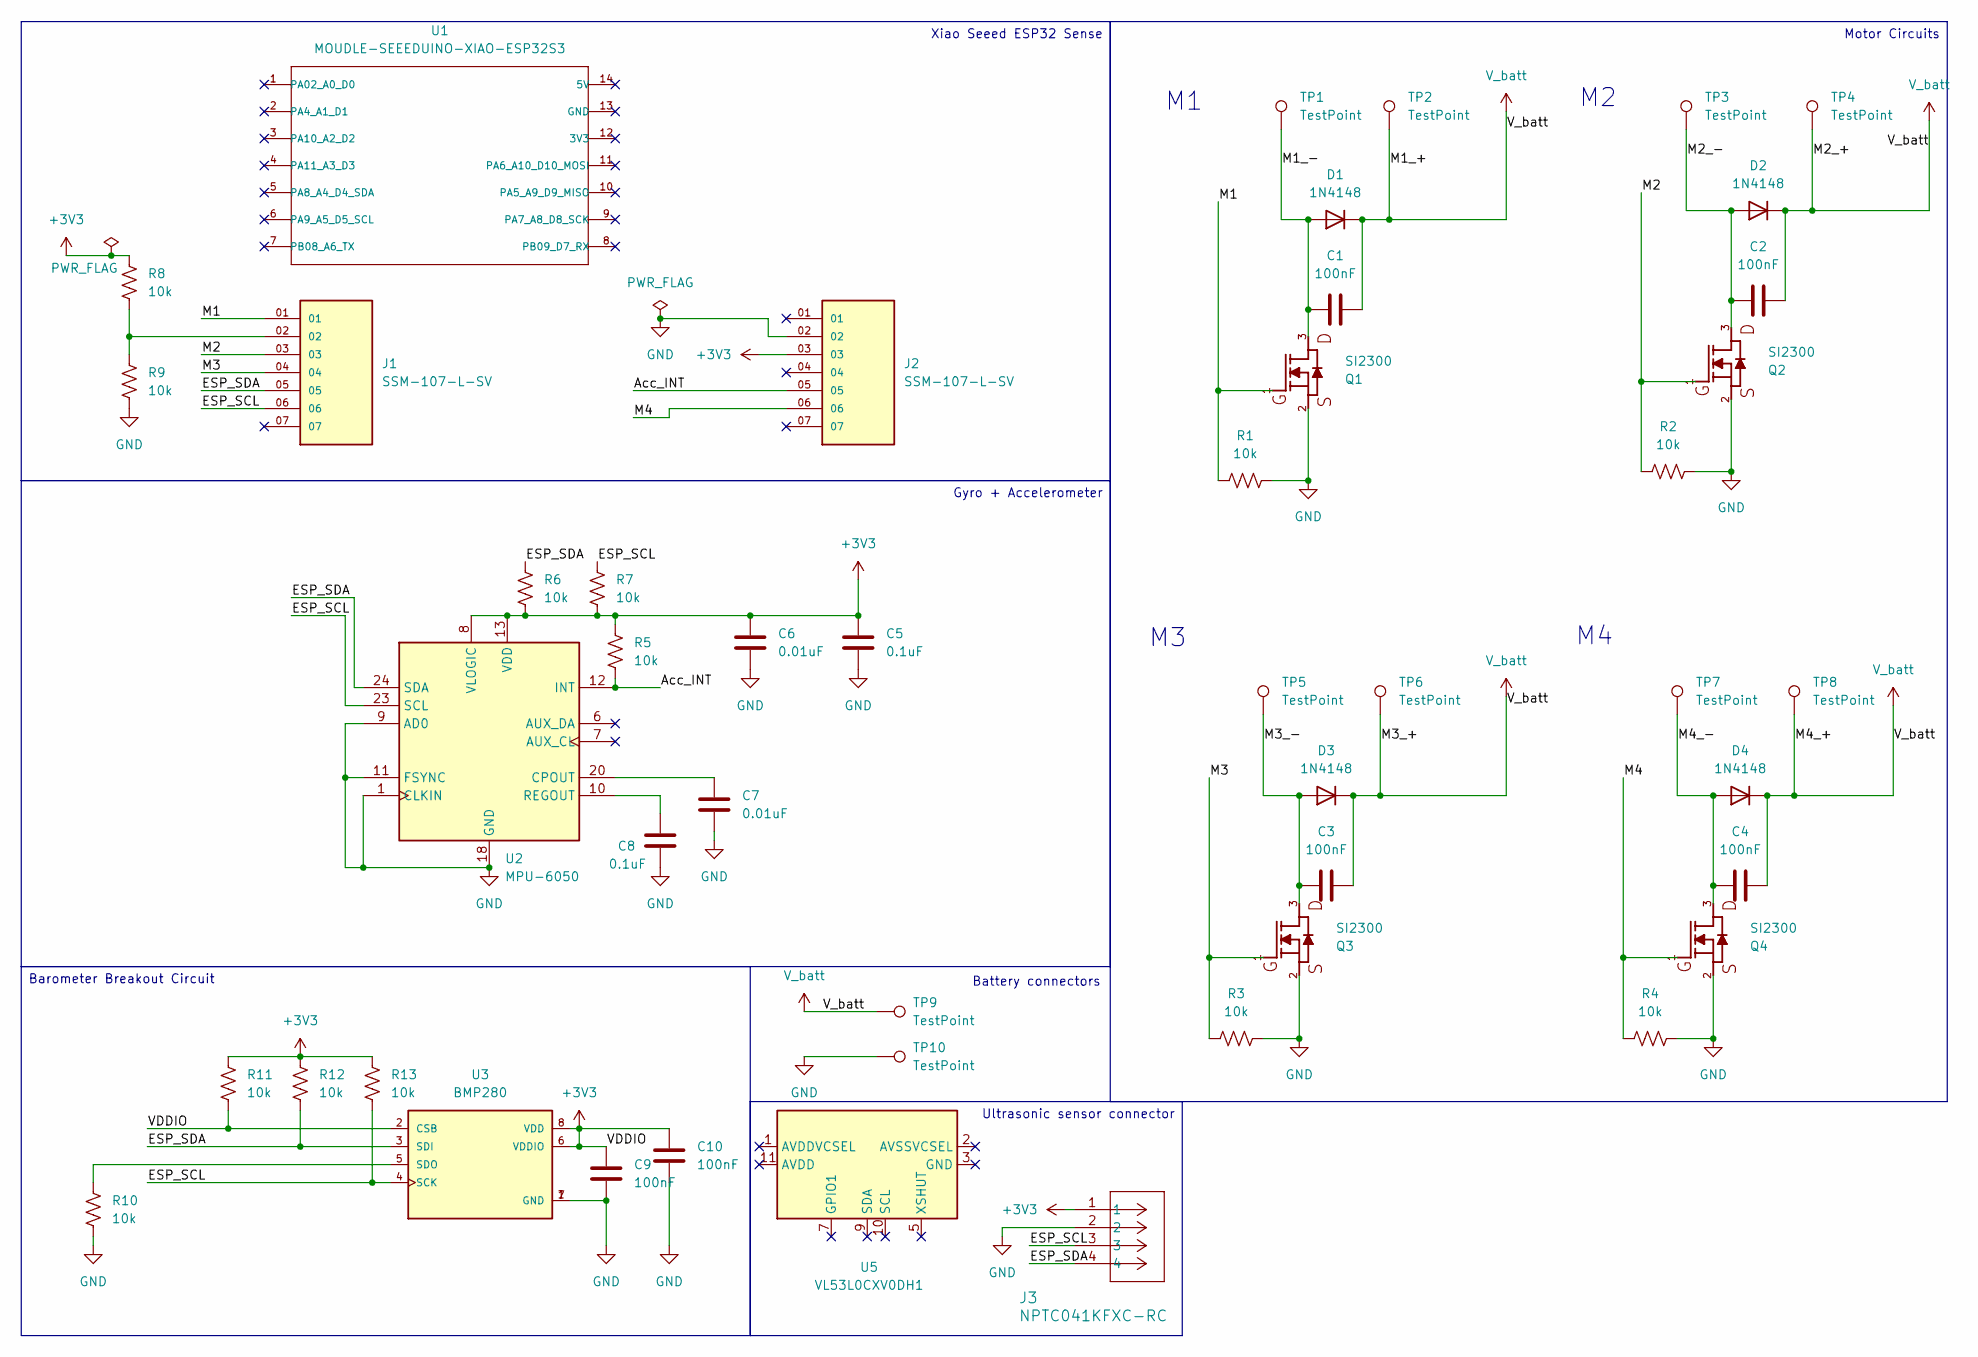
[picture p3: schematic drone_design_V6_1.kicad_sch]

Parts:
C1, C2, C3, C4, C9, C10: 100nF; C_0805_2012Metric
C5, C8: 0.1uF; C_0805_2012Metric
C6, C7: 0.01uF; C_0805_2012Metric
D1, D2, D3, D4: 1N4148; D_SOD-123
J1, J2: SSM-107-L-SV; SAMTEC_SSM-107-L-SV
J3: NPTC041KFXC-RC; CONN4X1_NPTC041KFXC-RC_SUL
Q1, Q2, Q3, Q4: SI2300; SOT-23
R1, R2, R3, R4, R5, R6, R7, R8, R9, R10, R11, R12, R13: 10k; C_0805_2012Metric
TP1, TP2, TP3, TP4, TP5, TP6, TP7, TP8: TestPoint; TestPoint_Pad_D1.5mm
TP9, TP10: TestPoint; TestPoint_Pad_D1.0mm
U1: MOUDLE-SEEEDUINO-XIAO-ESP32S3; MOUDLE14P-SMD-2.54-21X17.8MM
U2: MPU-6050; InvenSense_QFN-24_4x4mm_P0.5mm
U3: BMP280; XDCR_BMP280; PART_REV 1.19
U5: VL53L0CXV0DH1; ST_VL53L1x

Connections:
+3V3: C5.1, C6.1, C9.1, C10.1, J2.03, J3.1, R5.1, R6.2, R7.2, R8.2, R11.1, R11.2, R12.1, R13.1, U2.8 (VLOGIC), U2.13 (VDD), U3.2 (CSB), U3.6 (VDDIO), U3.8 (VDD)
/Acc_INT: J2.05, R5.2, U2.12 (INT)
/ESP_SCL: J1.06, J3.3, R7.1, R13.2, U2.23 (SCL), U3.4 (SCK)
/ESP_SDA: J1.05, J3.4, R6.1, R12.2, U2.24 (SDA), U3.3 (SDI)
/M1: J1.01, Q1.1, R1.1
/M1_-: C1.1, D1.2 (A), Q1.3, TP1.1
/M2: J1.03, Q2.1, R2.1
/M2_-: C2.1, D2.2 (A), Q2.3, TP3.1
/M3: J1.04, Q3.1, R3.1
/M3_-: C3.1, D3.2 (A), Q3.3, TP5.1
/M4: J2.06, Q4.1, R4.1
/M4_-: C4.1, D4.2 (A), Q4.3, TP7.1
GND: C5.2, C6.2, C7.2, C8.2, C9.2, C10.2, J2.02, J3.2, Q1.2, Q2.2, Q3.2, Q4.2, R1.2, R2.2, R3.2, R4.2, R9.1, R10.2, TP10.1, U2.1 (CLKIN), U2.9 (AD0), U2.11 (FSYNC), U2.18 (GND), U3.1 (GND), U3.7 (GND)
unnamed: J1.02, R8.1, R9.2
unnamed: C7.1, U2.20 (CPOUT)
unnamed: C8.1, U2.10 (REGOUT)
unnamed: R10.1, U3.5 (SDO)
unnamed: U5.3 (GND), U5.4 (GND), U5.6 (GND), U5.12 (GND)
V_batt: C1.2, C2.2, C3.2, C4.2, D1.1 (K), D2.1 (K), D3.1 (K), D4.1 (K), TP2.1, TP4.1, TP6.1, TP8.1, TP9.1

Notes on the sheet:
Battery connectors
Ultrasonic sensor connector
Gyro + Accelerometer
Xiao Seeed ESP32 Sense
Barometer Breakout Circuit
Motor Circuits

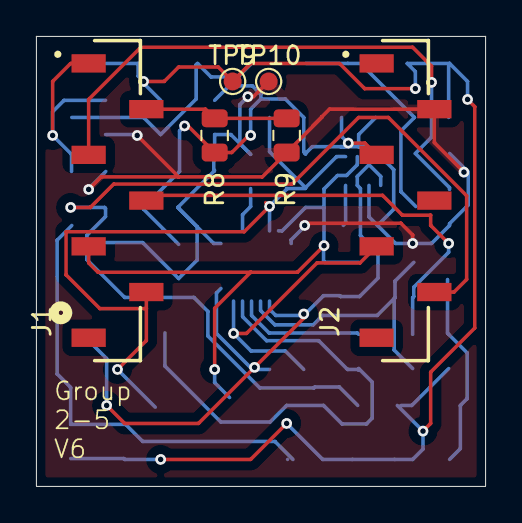
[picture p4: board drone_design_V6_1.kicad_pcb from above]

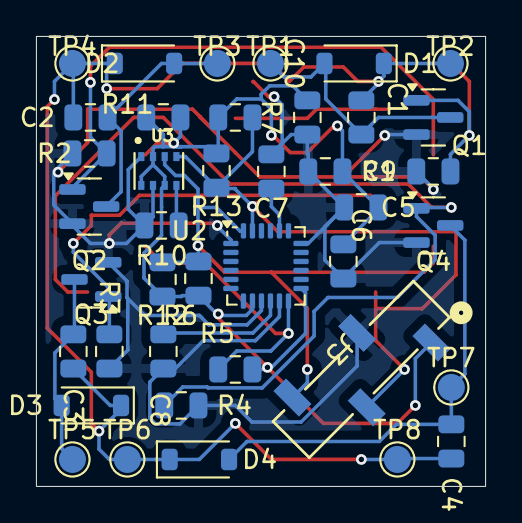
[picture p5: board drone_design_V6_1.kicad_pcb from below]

Board: 2 copper layers, 25.0 x 25.0 mm, 46 parts (40 on the bottom side), 18 nets.

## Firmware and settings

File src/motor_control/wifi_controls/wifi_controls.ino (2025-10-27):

#include <Arduino.h>
#include <Wire.h>
#include <VL53L0X.h>
#include <WiFi.h>
#include <WebServer.h>

// --- ESC pins (quad-X layout) ---
#define ESC1_PIN 25 //Front left
#define ESC2_PIN 26 //Front right
#define ESC3_PIN 27 //Back right
#define ESC4_PIN 14 //Back left

// --- ToF pins (ESP32) ---
#define SDA_PIN 21
#define SCL_PIN 22

// --- Constants ---
const uint32_t PWM_FREQ = 500;
const uint8_t  PWM_RES  = 16;

// Hover throttle and motion offsets (microseconds)
uint16_t baseThrottle = 1500;

// --- ToF Sensor ---
VL53L0X sensor;

// --- State Flags ---
bool motorsArmed = false;
bool obstacleDetected = false;
bool emergencyActive = false;
unsigned long obstacleStartTime = 0;

// --- Connection Watchdog ---
unsigned long lastClientTime = 0;
unsigned long armTime = 0;
bool clientConnected = false;
const unsigned long CONNECTION_TIMEOUT_MS = 2000;  // 2 seconds
const unsigned long ARM_GRACE_PERIOD_MS   = 3000;  // 3 seconds after arming

// --- Wi-Fi Access Point ---
const char* ap_ssid = "ESP32_DRONE";
const char* ap_password = "drone1234";
WebServer server(80);

// --- SPEED CONTROL ---
enum SpeedMode { SPEED_LOW = 0, SPEED_MEDIUM = 1, SPEED_HIGH = 2 };
SpeedMode currentSpeed = SPEED_MEDIUM; // default
uint16_t pitchOffset[] = {200, 350, 500};
uint16_t rollOffset[]  = {200, 350, 500};
uint16_t yawOffset[]   = {200, 350, 500};

// --- UI Mode Label ---
String currentMode = "Idle"; // simple label for web UI

// -------------------------------------------------------------------
uint32_t usToDuty(uint16_t us) {
  uint32_t period = 1000000UL / PWM_FREQ;
  if (us > period) us = period;
  const uint32_t max_duty = (1UL << PWM_RES) - 1;
  return (uint64_t)us * max_duty / period;
}

void writeESC(uint8_t pin, uint16_t us) {
  ledcWrite(pin, usToDuty(constrain(us, 1000, 2000)));
}

void setMotors(uint16_t m1, uint16_t m2, uint16_t m3, uint16_t m4) {
  writeESC(ESC1_PIN, m1);
  writeESC(ESC2_PIN, m2);
  writeESC(ESC3_PIN, m3);
  writeESC(ESC4_PIN, m4);
}

void hover() {
  setMotors(baseThrottle, baseThrottle, baseThrottle, baseThrottle);
  currentMode = "Hover";
}

void stopMotors() {
  if (emergencyActive) return;
  emergencyActive = true;
  motorsArmed = false;

  Serial.println(" Emergency landing initiated...");

  uint16_t throttle = baseThrottle;
  unsigned long lastUpdate = millis();

  while (throttle > 800) {
    setMotors(throttle, throttle, throttle, throttle);
    server.handleClient();
    if (millis() - lastUpdate >= 500) {
      Serial.printf("Throttle: %d\n", throttle);
      lastUpdate = millis();
    }
    throttle -= 10;
    delay(200);
  }

  setMotors(800, 800, 800, 800);
  delay(1500);

  ledcDetach(ESC1_PIN);
  ledcDetach(ESC2_PIN);
  ledcDetach(ESC3_PIN);
  ledcDetach(ESC4_PIN);

  Serial.println("Motors detached — full stop.");
  currentMode = "Emergency STOP";
}

void armMotors() {
  if (motorsArmed) return;

  Serial.println("Arming motors... ramping up throttle.");
  uint8_t pins[4] = {ESC1_PIN, ESC2_PIN, ESC3_PIN, ESC4_PIN};
  for (uint8_t i = 0; i < 4; i++) {
    ledcAttach(pins[i], PWM_FREQ, PWM_RES);
  }

  uint16_t throttle = 900;
  while (throttle < baseThrottle) {
    setMotors(throttle, throttle, throttle, throttle);
    Serial.printf("Throttle: %d\n", throttle);
    throttle += 10;
    delay(200);
  }

  hover();
  motorsArmed = true;
  emergencyActive = false;
  armTime = millis(); // record time of arming
  Serial.println("Motors armed and hovering.");
  currentMode = "Armed - Hover";
}

// --- Motion Functions ---
void moveForward() {
  uint16_t dp = pitchOffset[currentSpeed];
  setMotors(baseThrottle - dp, baseThrottle - dp, baseThrottle + dp, baseThrottle + dp);
  currentMode = "Moving Forward";
}
void moveBackward() {
  uint16_t dp = pitchOffset[currentSpeed];
  setMotors(baseThrottle + dp, baseThrottle + dp, baseThrottle - dp, baseThrottle - dp);
  currentMode = "Moving Backward";
}
void moveLeft() {
  uint16_t dr = rollOffset[currentSpeed];
  setMotors(baseThrottle - dr, baseThrottle + dr, baseThrottle + dr, baseThrottle - dr);
  currentMode = "Moving Left";
}
void moveRight() {
  uint16_t dr = rollOffset[currentSpeed];
  setMotors(baseThrottle + dr, baseThrottle - dr, baseThrottle - dr, baseThrottle + dr);
  currentMode = "Moving Right";
}
void rotateLeft() {
  uint16_t dy = yawOffset[currentSpeed];
  setMotors(baseThrottle - dy, baseThrottle + dy, baseThrottle - dy, baseThrottle + dy);
  currentMode = "Rotating Left";
}
void rotateRight() {
  uint16_t dy = yawOffset[currentSpeed];
  setMotors(baseThrottle + dy, baseThrottle - dy, baseThrottle + dy, baseThrottle - dy);
  currentMode = "Rotating Right";
}

// --- Pentagon path ---
void pentagonPath() {
  Serial.println("Starting pentagon path...");
  const int sides = 5;
  const int forwardTimeMs = 3000;
  const int rotateTimeMs = 1000;

  for (int i = 0; i < sides; i++) {
    if (emergencyActive || obstacleDetected) break;
    Serial.printf("Pentagon side %d: moving forward\n", i + 1);
    moveForward();
    delay(forwardTimeMs);

    Serial.printf("Pentagon side %d: rotating 72 deg\n", i + 1);
    rotateRight();
    delay(rotateTimeMs);

    hover();
    delay(500);
  }

  Serial.println("Pentagon path complete.");
  hover();
}

bool motionAllowed() {
  return (!emergencyActive && motorsArmed && !obstacleDetected);
}

// --- Connection heartbeat refresh ---
void refreshClientConnection() {
  lastClientTime = millis();
  clientConnected = true;
}

// --- Web Handlers ---
void handleArm() { refreshClientConnection(); server.send(200, "text/plain", "Arming motors..."); armMotors(); }
void handleHover() { refreshClientConnection(); if (!motionAllowed()) { server.send(200, "text/plain", "Cannot hover."); return; } hover(); server.send(200, "text/plain", "Hovering."); }
void handleForward() { refreshClientConnection(); if (!motionAllowed()) { server.send(200, "text/plain", "Blocked"); return; } moveForward(); server.send(200, "text/plain", "Forward"); }
void handleBackward() { refreshClientConnection(); if (!motionAllowed()) { server.send(200, "text/plain", "Blocked"); return; } moveBackward(); server.send(200, "text/plain", "Backward"); }
void handleLeft() { refreshClientConnection(); if (!motionAllowed()) { server.send(200, "text/plain", "Blocked"); return; } moveLeft(); server.send(200, "text/plain", "Left"); }
void handleRight() { refreshClientConnection(); if (!motionAllowed()) { server.send(200, "text/plain", "Blocked"); return; } moveRight(); server.send(200, "text/plain", "Right"); }
void handleRotLeft() { refreshClientConnection(); if (!motionAllowed()) { server.send(200, "text/plain", "Blocked"); return; } rotateLeft(); server.send(200, "text/plain", "Rotate Left"); }
void handleRotRight() { refreshClientConnection(); if (!motionAllowed()) { server.send(200, "text/plain", "Blocked"); return; } rotateRight(); server.send(200, "text/plain", "Rotate Right"); }
void handlePentagon() { refreshClientConnection(); if (!motionAllowed()) { server.send(200, "text/plain", "Blocked"); return; } server.send(200, "text/plain", "Pentagon started"); pentagonPath(); }
void handleSpeed() {
  refreshClientConnection();
  if (!server.hasArg("mode")) { server.send(400, "text/plain", "Missing mode"); return; }
  String m = server.arg("mode");
  if (m == "0") currentSpeed = SPEED_LOW;
  else if (m == "1") currentSpeed = SPEED_MEDIUM;
  else if (m == "2") currentSpeed = SPEED_HIGH;
  else { server.send(400, "text/plain", "Bad mode"); return; }
  server.send(200, "text/plain", "Speed set");
}
void handleKill() { refreshClientConnection(); server.send(200, "text/plain", "KILL activated"); stopMotors(); }

void handleStatus() {
  refreshClientConnection();
  uint16_t distance = sensor.readRangeContinuousMillimeters();
  float distance_cm = (distance / 10.0)-2.0;
  if (distance_cm < 0) distance_cm = 0;

  String json = "{";
  json += "\"motorsArmed\":"; json += (motorsArmed ? "true" : "false"); json += ",";
  json += "\"emergencyActive\":"; json += (emergencyActive ? "true" : "false"); json += ",";
  json += "\"obstacleDetected\":"; json += (obstacleDetected ? "true" : "false"); json += ",";
  json += "\"currentSpeed\":"; json += (int)currentSpeed; json += ",";
  json += "\"mode\":\""; json += currentMode; json += "\",";
  json += "\"distance_cm\":"; json += String(distance_cm, 1);
  json += "}";
  server.send(200, "application/json", json);
}

void handleRoot() {
  refreshClientConnection();
  String page =
    "<!doctype html><html><head><meta name='viewport' content='width=device-width,initial-scale=1'/>"
    "<title>ESP32 Drone Control</title></head><body>"
    "<h2>ESP32 Drone Control (AP Mode)</h2>"
    "<div id='status'>Loading...</div>"
    "<div style='margin-top:10px;'>"
    "<button onclick=\"cmd('/arm')\">Arm</button> "
    "<button onclick=\"cmd('/hover')\">Hover</button> "
    "<button onclick=\"cmd('/forward')\">Forward</button> "
    "<button onclick=\"cmd('/back')\">Backward</button> "
    "<button onclick=\"cmd('/left')\">Left</button> "
    "<button onclick=\"cmd('/right')\">Right</button> "
    "<button onclick=\"cmd('/rotleft')\">Rotate Left</button> "
    "<button onclick=\"cmd('/rotright')\">Rotate Right</button> "
    "<button onclick=\"cmd('/pentagon')\">Pentagon</button>"
    "</div>"
    "<div style='margin-top:12px;'>"
    "Speed: <button onclick=\"cmd('/speed?mode=0')\">Low</button> "
    "<button onclick=\"cmd('/speed?mode=1')\">Medium</button> "
    "<button onclick=\"cmd('/speed?mode=2')\">High</button>"
    "</div>"
    "<div style='margin-top:12px;'>"
    "<button style='background:red;color:white;padding:10px' onclick=\"cmd('/kill')\">KILL</button>"
    "</div>"
    "<script>"
    "function cmd(p){var x=new XMLHttpRequest();x.open('GET',p,true);x.send();}"
    "function update(){var r=new XMLHttpRequest();r.open('GET','/status',true);"
    "r.onreadystatechange=function(){if(r.readyState==4){if(r.status==200){"
    "var s=JSON.parse(r.responseText);"
    "var html='Mode: '+s.mode+'<br>Speed: '+(s.currentSpeed==0?'LOW':(s.currentSpeed==1?'MEDIUM':'HIGH'))+"
    "'<br>Armed: '+s.motorsArmed+'<br>Emergency: '+s.emergencyActive+'<br>Obstacle: '+s.obstacleDetected+"
    "'<br>Distance (cm): '+s.distance_cm;document.getElementById('status').innerHTML=html;}"
    "setTimeout(update,500);}};r.send();}"
    "update();</script></body></html>";
  server.send(200, "text/html", page);
}

// -------------------------------------------------------------------
void setup() {
  Serial.begin(115200);

  uint8_t pins[4] = {ESC1_PIN, ESC2_PIN, ESC3_PIN, ESC4_PIN};
  for (uint8_t i = 0; i < 4; i++) {
    ledcAttach(pins[i], PWM_FREQ, PWM_RES);
  }

  Serial.println("Motors are OFF. Web controls available on AP only.");

  Wire.begin(SDA_PIN, SCL_PIN);
  if (!sensor.init()) {
    Serial.println("Failed to detect and initialize VL53L0X!");
    while (1) {}
  }

  sensor.setMeasurementTimingBudget(20000);
  sensor.startContinuous();

  // --- Wi-Fi Access Point setup ---
  Serial.println("\nStarting Wi-Fi Access Point...");
  WiFi.softAP(ap_ssid, ap_password);
  IPAddress IP = WiFi.softAPIP();
  Serial.print(" Access Point started. Connect to SSID: ");
  Serial.println(ap_ssid);
  Serial.print("Password: ");
  Serial.println(ap_password);
  Serial.print("Then open in browser: http://");
  Serial.println(IP);

  // --- Web Server routes ---
  server.on("/", handleRoot);
  server.on("/status", handleStatus);
  server.on("/arm", handleArm);
  server.on("/hover", handleHover);
  server.on("/forward", handleForward);
  server.on("/back", handleBackward);
  server.on("/left", handleLeft);
  server.on("/right", handleRight);
  server.on("/rotleft", handleRotLeft);
  server.on("/rotright", handleRotRight);
  server.on("/pentagon", handlePentagon);
  server.on("/speed", handleSpeed);
  server.on("/kill", handleKill);

  server.begin();
  Serial.println("Web server started.");
  Serial.println("Ready. Controls are on the Wi-Fi page only (AP mode).");

  lastClientTime = millis();  // initialize watchdog timer
}

// -------------------------------------------------------------------
void loop() {
  server.handleClient();

  uint16_t distance = sensor.readRangeContinuousMillimeters();
  float distance_cm = (distance / 10.0) - 2.0;
  if (distance_cm < 0) distance_cm = 0;
  Serial.print("Distance: "); Serial.print(distance_cm); Serial.println(" cm");

  // --- Obstacle detection ---
  if (!emergencyActive && motorsArmed) {
    if (distance_cm <= 10.0 && distance_cm > 0) {
      if (!obstacleDetected) {
        obstacleDetected = true;
        obstacleStartTime = millis();
        Serial.println(" Obstacle detected — hovering.");
        hover();
      } else if (millis() - obstacleStartTime >= 10000) {
        Serial.println(" Obstacle persists 10 s — triggering EMERGENCY STOP!");
        stopMotors();
      }
    } else {
      if (obstacleDetected) {
        obstacleDetected = false;
        Serial.println(" Obstacle cleared — control re-enabled.");
      }
    }
  }

  // --- Connection watchdog (fixed logic) ---
  if (motorsArmed && !emergencyActive) {
    unsigned long now = millis();

    // Ignore timeout for a few seconds after arming
    if (now - armTime > ARM_GRACE_PERIOD_MS) {
      if (clientConnected && (now - lastClientTime > CONNECTION_TIMEOUT_MS)) {
        Serial.println(" Web client inactive — initiating EMERGENCY STOP!");
        stopMotors();
      }
    }
  }

  if (sensor.timeoutOccurred()) Serial.println("Sensor timeout!");
  delay(100);
}

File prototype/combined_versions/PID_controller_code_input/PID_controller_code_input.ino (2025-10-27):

/*
  ESP32 + MPU6050 — Yaw Rate Control with PID (no Serial input)
  -------------------------------------------------------------
  You can directly set control parameters below:
    • targetYawRate   -> rad/s (positive = spin right, negative = spin left)
    • kP_yaw, kI_yaw, kD_yaw -> PID gains
    • baseThrottle    -> base ESC throttle (1000–2000 µs)
*/

#include <Arduino.h>
#include <Wire.h>
#include <Adafruit_MPU6050.h>
#include <Adafruit_Sensor.h>

// ---------- ESC pins ----------
#define ESC1_PIN 25   // Front-Left  (M1)
#define ESC2_PIN 26   // Front-Right (M2)
#define ESC3_PIN 27   // Rear-Right  (M3)
#define ESC4_PIN 14   // Rear-Left   (M4)

// ---------- PWM setup ----------
const uint32_t PWM_FREQ = 500;   // Hz
const uint8_t  PWM_RES  = 16;    // bits

// ---------- Throttle ----------
uint16_t baseThrottle = 1500;    // hover throttle
const uint16_t MIN_US = 1000;
const uint16_t MAX_US = 2000;

// ---------- Motor spin directions ----------
const bool M1_CCW = true;
const bool M2_CCW = false;
const bool M3_CCW = true;
const bool M4_CCW = false;

// ---------- Gyro ----------
Adafruit_MPU6050 mpu;

// ---------- PID parameters ----------
float kP_yaw = 120.0f;  // proportional gain
float kI_yaw = 20.0f;   // integral gain
float kD_yaw = 5.0f;    // derivative gain

// ---------- Control targets ----------
float targetYawRate = 0.0f;   // rad/s (e.g. 1.0 = spin right, -1.0 = spin left)

// ---------- PID state ----------
float yawIntegral = 0.0f;
float lastError = 0.0f;

// Utility: microseconds -> LEDC duty (ESP32)
uint32_t usToDuty(uint16_t us) {
  uint32_t period = 1000000UL / PWM_FREQ;
  if (us < MIN_US) us = MIN_US;
  if (us > MAX_US) us = MAX_US;
  const uint32_t max_duty = (1UL << PWM_RES) - 1;
  return (uint64_t)us * max_duty / period;
}

// Write one ESC by pin
void writeESC(uint8_t pin, uint16_t us) {
  ledcWrite(pin, usToDuty(us));
}

// Mix yaw correction into motors
void mixYawAndWrite(int16_t yawMixUs) {
  int16_t m1 = baseThrottle + (M1_CCW ? +yawMixUs : -yawMixUs);
  int16_t m2 = baseThrottle + (M2_CCW ? +yawMixUs : -yawMixUs);
  int16_t m3 = baseThrottle + (M3_CCW ? +yawMixUs : -yawMixUs);
  int16_t m4 = baseThrottle + (M4_CCW ? +yawMixUs : -yawMixUs);

  writeESC(ESC1_PIN, m1);
  writeESC(ESC2_PIN, m2);
  writeESC(ESC3_PIN, m3);
  writeESC(ESC4_PIN, m4);
}

void setup() {
  Serial.begin(115200);
  delay(50);

  Serial.println(F("=== Yaw Rate PID Control (Fixed Settings) ==="));
  Serial.print(F("Target yaw rate: ")); Serial.print(targetYawRate); Serial.println(F(" rad/s"));
  Serial.print(F("Base throttle: ")); Serial.println(baseThrottle);
  Serial.print(F("PID gains: ")); Serial.print(kP_yaw); Serial.print(", ");
  Serial.print(kI_yaw); Serial.print(", "); Serial.println(kD_yaw);

  // ESC setup
  uint8_t pins[4] = {ESC1_PIN, ESC2_PIN, ESC3_PIN, ESC4_PIN};
  for (uint8_t i = 0; i < 4; i++) ledcAttach(pins[i], PWM_FREQ, PWM_RES);

  // Arm ESCs
  for (uint8_t i = 0; i < 4; i++) writeESC(pins[i], MIN_US);
  delay(2000);

  // MPU6050 setup
  Wire.begin(21, 22); // SDA=21, SCL=22
  if (!mpu.begin(0x68, &Wire)) {
    if (!mpu.begin(0x69, &Wire)) {
      Serial.println(F("[FATAL] MPU6050 not found. Check wiring!"));
      while (1) delay(10);
    }
  }
  mpu.setAccelerometerRange(MPU6050_RANGE_8_G);
  mpu.setGyroRange(MPU6050_RANGE_500_DEG);
  mpu.setFilterBandwidth(MPU6050_BAND_21_HZ);
  delay(100);
}

void loop() {
  // --- Read gyro yaw rate ---
  sensors_event_t a, g, temp;
  mpu.getEvent(&a, &g, &temp);
  float yawRate = g.gyro.z; // rad/s

  // --- PID controller ---
  float err = targetYawRate - yawRate;

  // Proportional
  float Pterm = kP_yaw * err;

  // Integral
  yawIntegral += err * 0.01f;
  yawIntegral = constrain(yawIntegral, -50.0f, 50.0f);
  float Iterm = kI_yaw * yawIntegral;

  // Derivative
  float derivative = (err - lastError) / 0.01f;
  float Dterm = kD_yaw * derivative;
  lastError = err;

  // Total PID output
  float yawMixF = Pterm + Iterm + Dterm;
  yawMixF = constrain(yawMixF, -200, 200);

  // Apply to motors
  mixYawAndWrite((int16_t)yawMixF);

  // Telemetry
  static uint32_t lastPrint = 0;
  if (millis() - lastPrint > 250) {
    lastPrint = millis();
    Serial.print("YawRate(rad/s): "); Serial.print(yawRate, 3);
    Serial.print("  target: "); Serial.print(targetYawRate, 3);
    Serial.print("  P: "); Serial.print(Pterm, 1);
    Serial.print("  I: "); Serial.print(Iterm, 1);
    Serial.print("  D: "); Serial.print(Dterm, 1);
    Serial.print("  mix(us): "); Serial.print((int)yawMixF);
    Serial.print("  base(us): "); Serial.println(baseThrottle);
  }

  delay(10); // ~100 Hz loop
}

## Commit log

2025-10-24 Add initial PCB schematic file
2025-10-24 Update and rename PCB to note
2025-10-27 Add blank file in sensor_module directory
2025-10-27 Add new camera module file 'b'
